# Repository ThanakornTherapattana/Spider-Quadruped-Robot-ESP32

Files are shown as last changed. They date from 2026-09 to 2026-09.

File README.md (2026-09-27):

# Spider Quadruped Robot

I built this cute spider robot from scratch with esp32 and lots of determination. by trials and errors, this robot improve bit by bit...

this is still experimental project, not a finished one yet!

## Components
12 x mg996R servo
1 x esp32 wroom
1 x 7.4V 2200mAh lipo battery
2 x PCA9685 driver
1 x 3.3v buck converter
1 x 20A buck converter
2 x 2200uF 10V capacitor
1 x MPU6050
M2/M3 screws and heat insertion set
3D printed parts (can be download in 3D models folder)

## how to run
### 1) Servo calibration
I don't have the calibration file uploaded here but you can do it by setting Coxa and Femur joint to 90 degree and Tibia to 0 degree.
### 2) Assemble 
copy this image. the leg should be stretch out like this
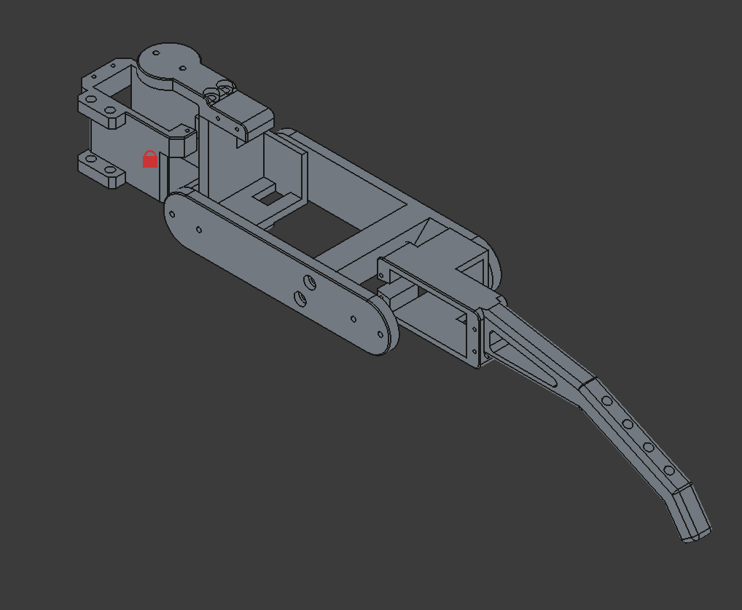
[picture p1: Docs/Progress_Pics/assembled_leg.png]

### 3) Movement TEST (No MPU6050 needed)
you can run the IK_test.ino file first for one leg.
the leg will follow a cycloidal curve to perform a step.
after that you can move-on to 1legs_test.ino (you have to fully assemble the robot)


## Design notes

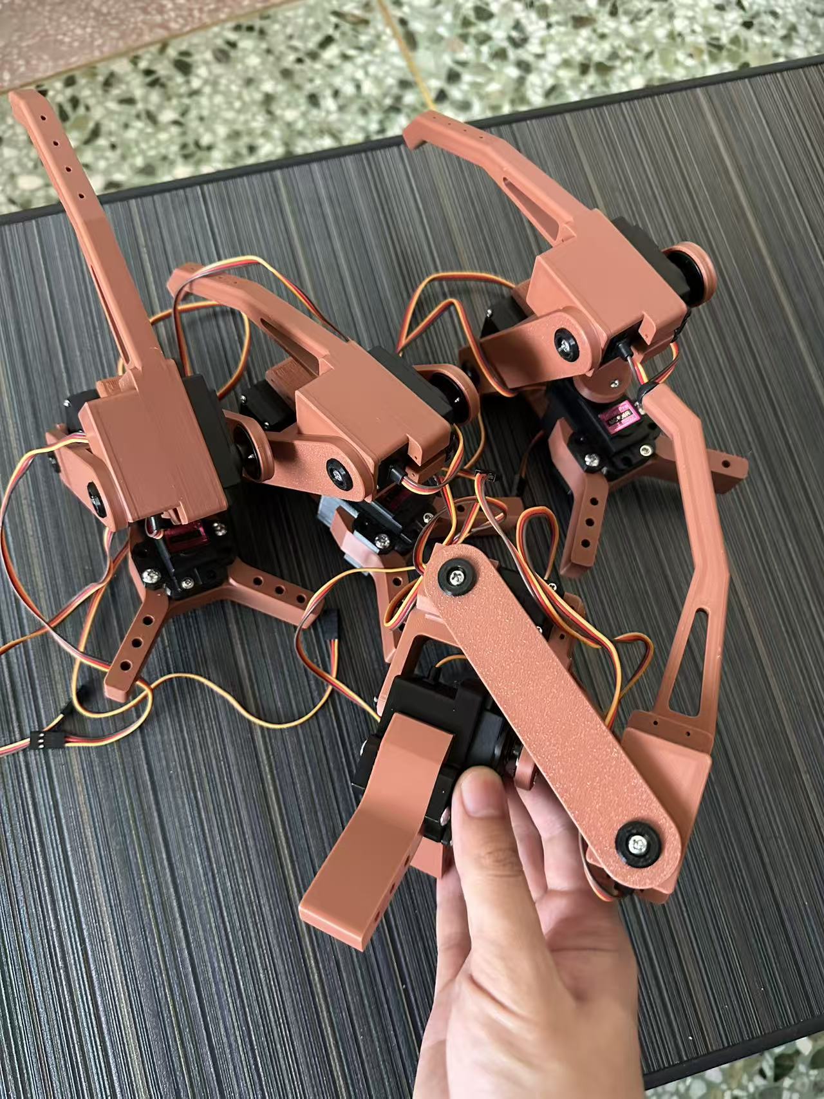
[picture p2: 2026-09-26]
Docs/Progress_Pics/Weixin Image_20260918160550_50_58.jpg

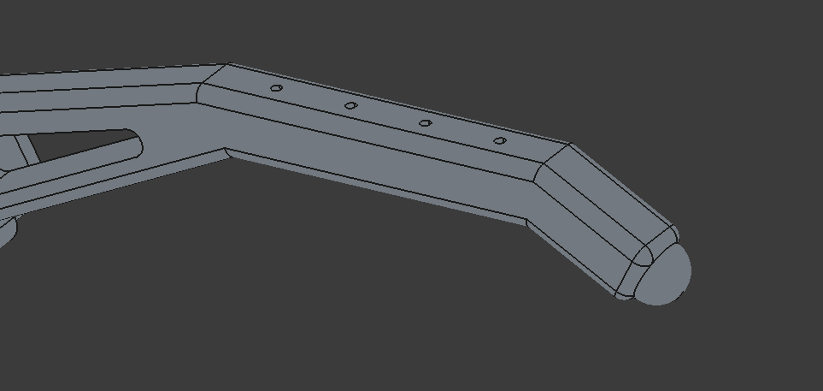
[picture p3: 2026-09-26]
Docs/Progress_Pics/Screenshot 2026-05-20 154046.png

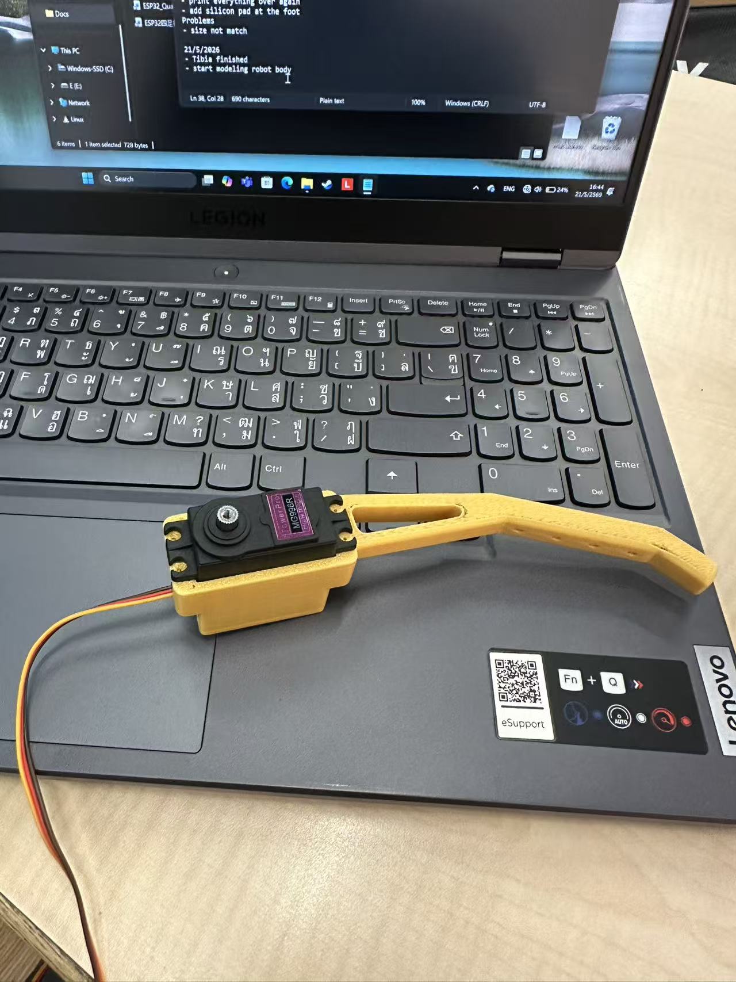
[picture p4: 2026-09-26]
Docs/Progress_Pics/Weixin Image_20260521164413_180_100.jpg

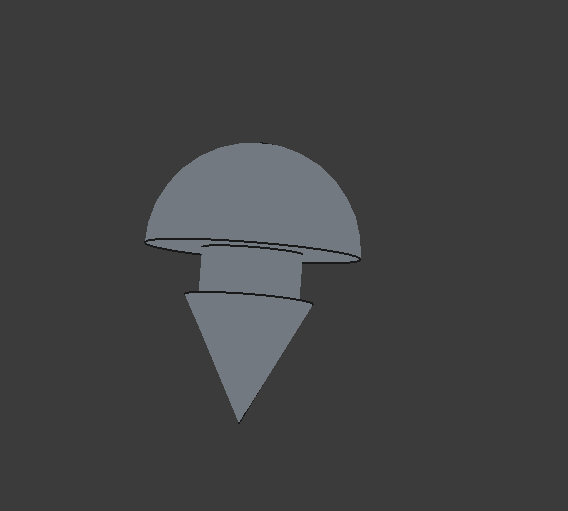
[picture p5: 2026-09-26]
Docs/Progress_Pics/Screenshot 2026-05-20 144256.png

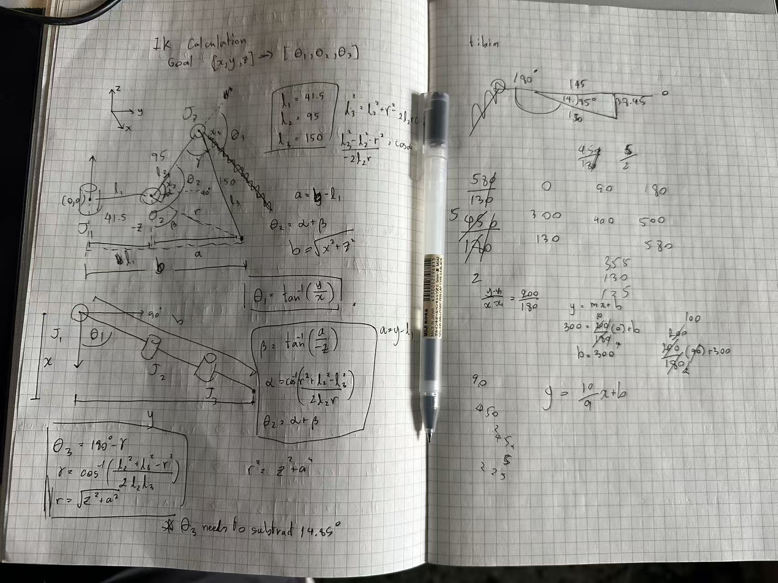
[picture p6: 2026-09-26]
Docs/Progress_Pics/Weixin Image_20260526165921_192_100.jpg

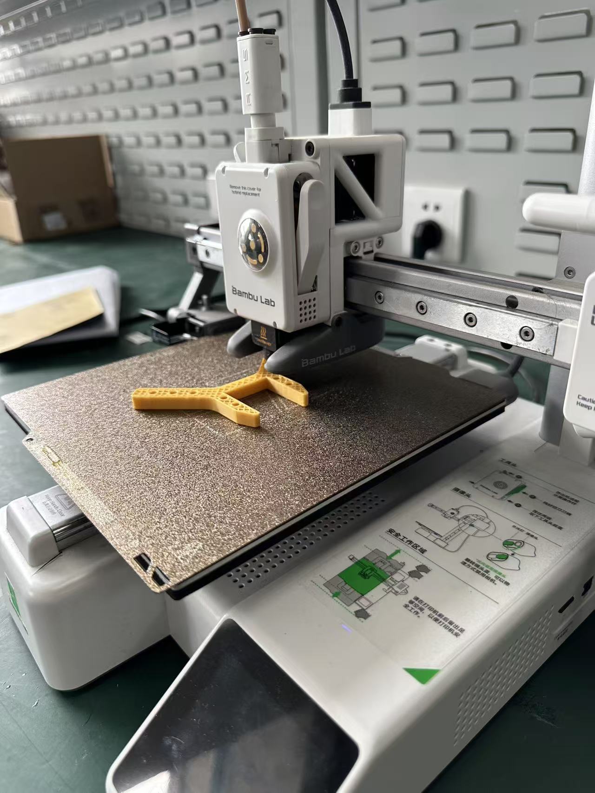
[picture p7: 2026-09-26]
Docs/Progress_Pics/Weixin Image_20260522120751_183_100.jpg

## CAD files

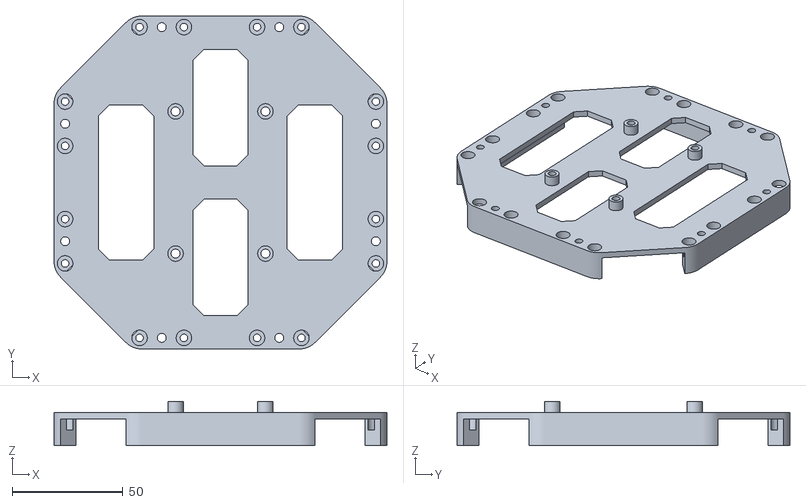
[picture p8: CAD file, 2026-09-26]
3D models/body_files/first_leg-bodyTop.stl
150.0 x 150.0 x 20.0

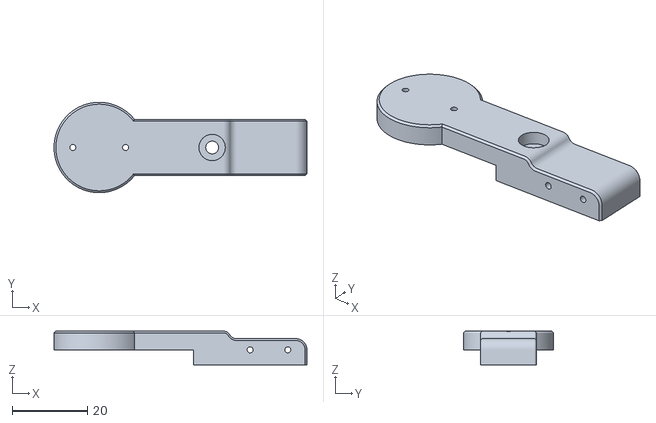
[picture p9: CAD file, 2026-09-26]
3D models/newPrint_files/first_leg-newCoxaTop.stl
67.2 x 24.0 x 9.00

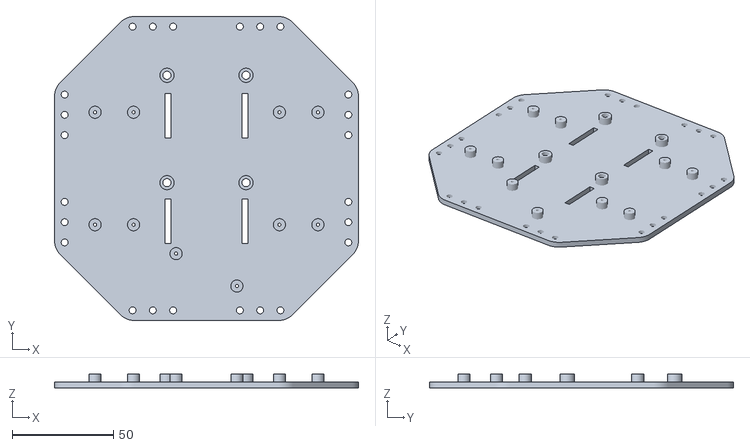
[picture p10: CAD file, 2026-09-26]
3D models/body_files/first_leg-bodyBottom.stl
150.0 x 150.0 x 7.00

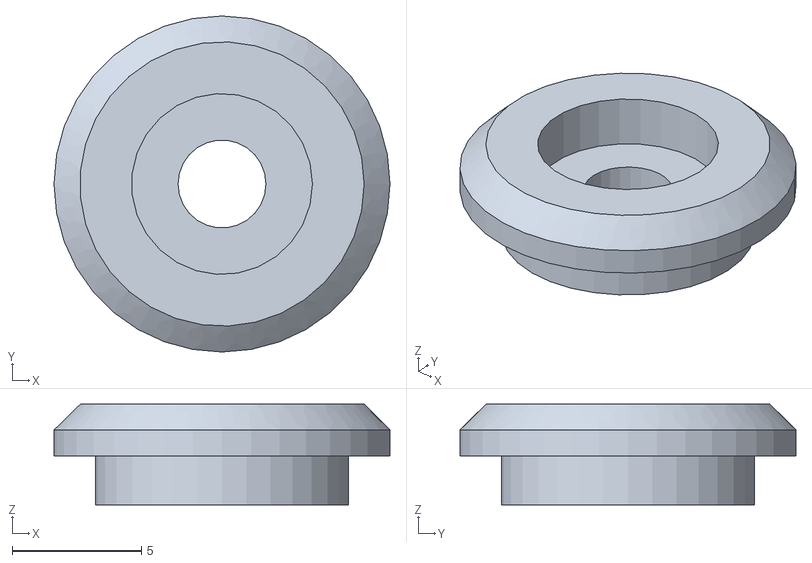
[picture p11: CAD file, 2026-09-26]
3D models/newPrint_files/first_leg-FrictionPad.stl
13.0 x 13.0 x 3.90

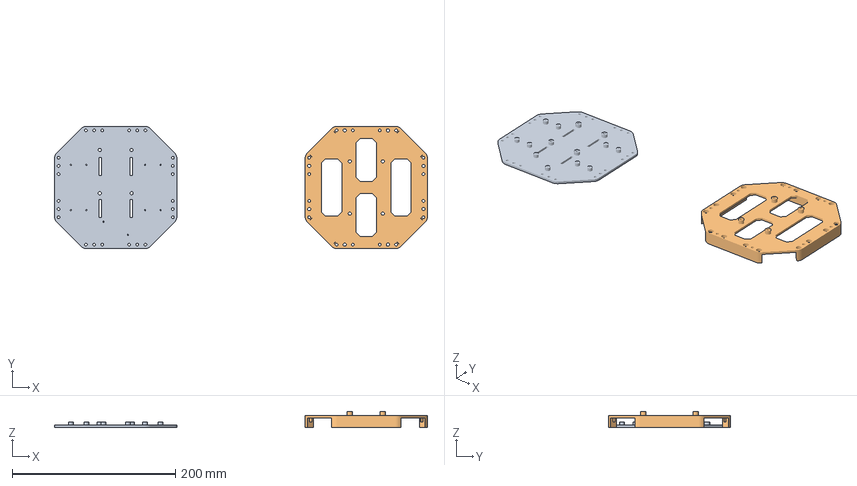
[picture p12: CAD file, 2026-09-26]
3D models/body_files/body_plates.3mf
457.2 x 150.0 x 20.0 mm
first_leg-bodyBottom.stl
first_leg-bodyTop.stl

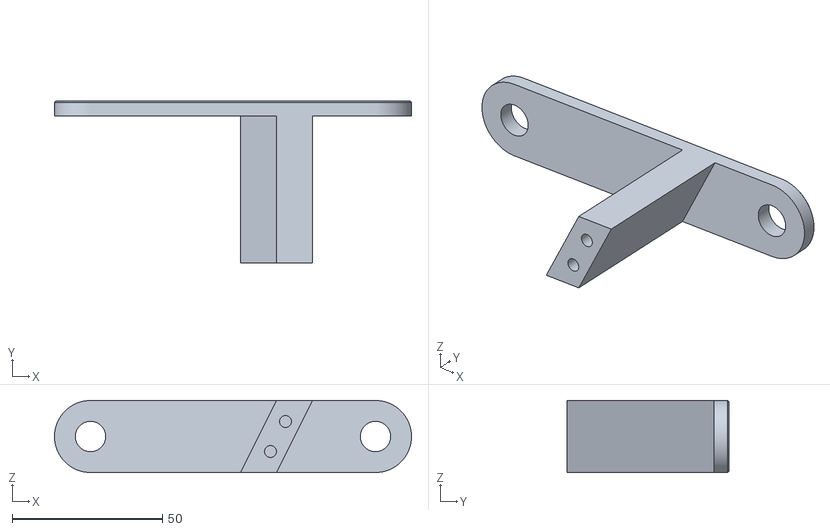
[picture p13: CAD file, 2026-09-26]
3D models/newPrint_files/first_leg-FemurBottom.stl
119.0 x 54.0 x 24.0

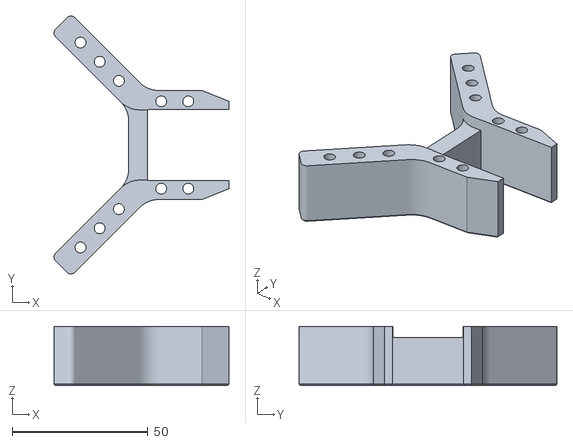
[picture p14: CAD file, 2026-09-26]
3D models/newPrint_files/first_leg-coxaHolder.stl
64.5 x 95.1 x 21.8

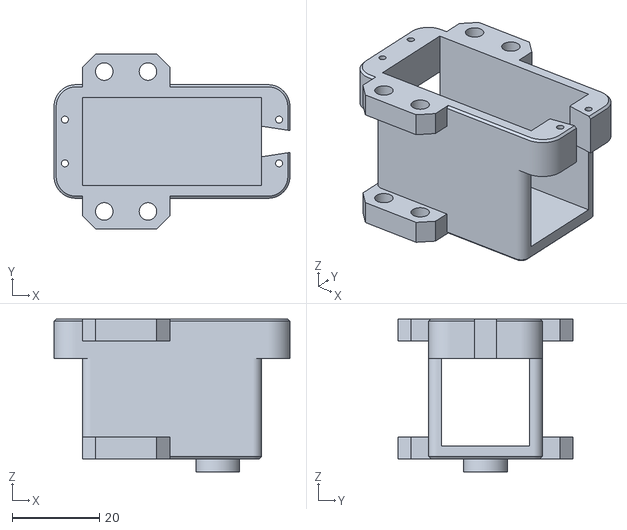
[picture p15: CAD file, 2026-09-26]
3D models/newPrint_files/first_leg-newCoxaServoMount.stl
54.0 x 40.0 x 35.0

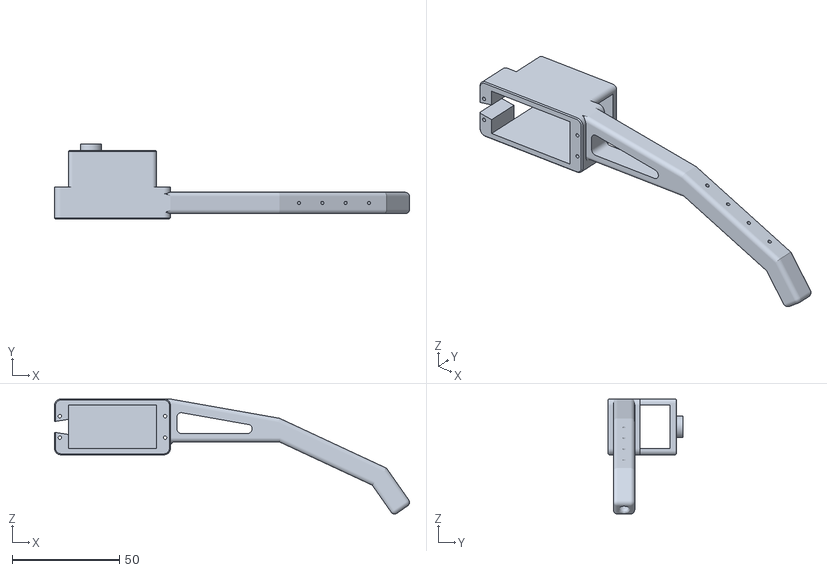
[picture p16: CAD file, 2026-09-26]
3D models/newPrint_files/first_leg-newTibia001.stl
165.3 x 35.0 x 53.5

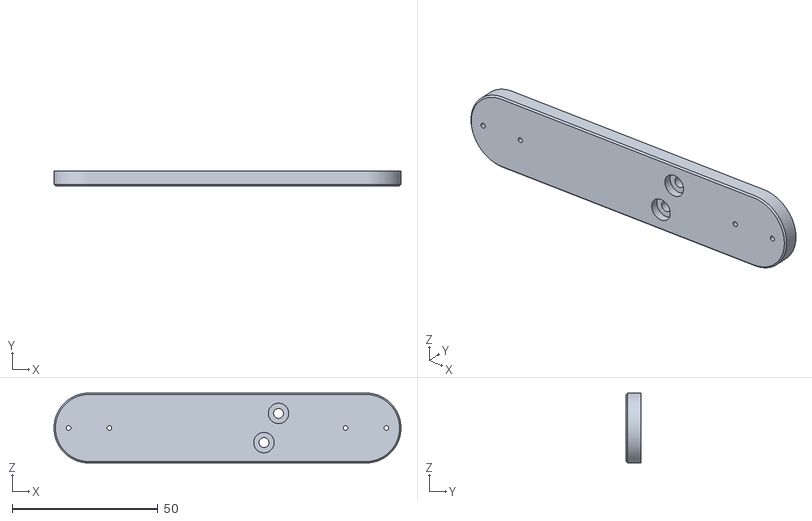
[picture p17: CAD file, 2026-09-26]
3D models/newPrint_files/first_leg-FemurTop.stl
119.0 x 5.00 x 24.0

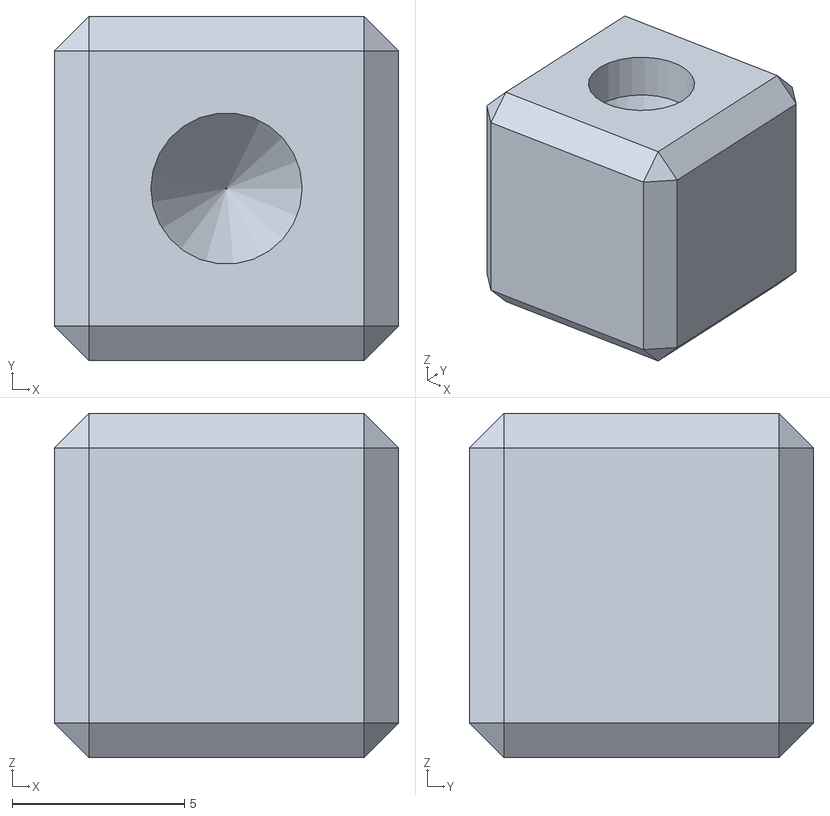
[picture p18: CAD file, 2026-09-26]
3D models/newPrint_files/footPadtest-Body.stl
10.0 x 10.0 x 10.0

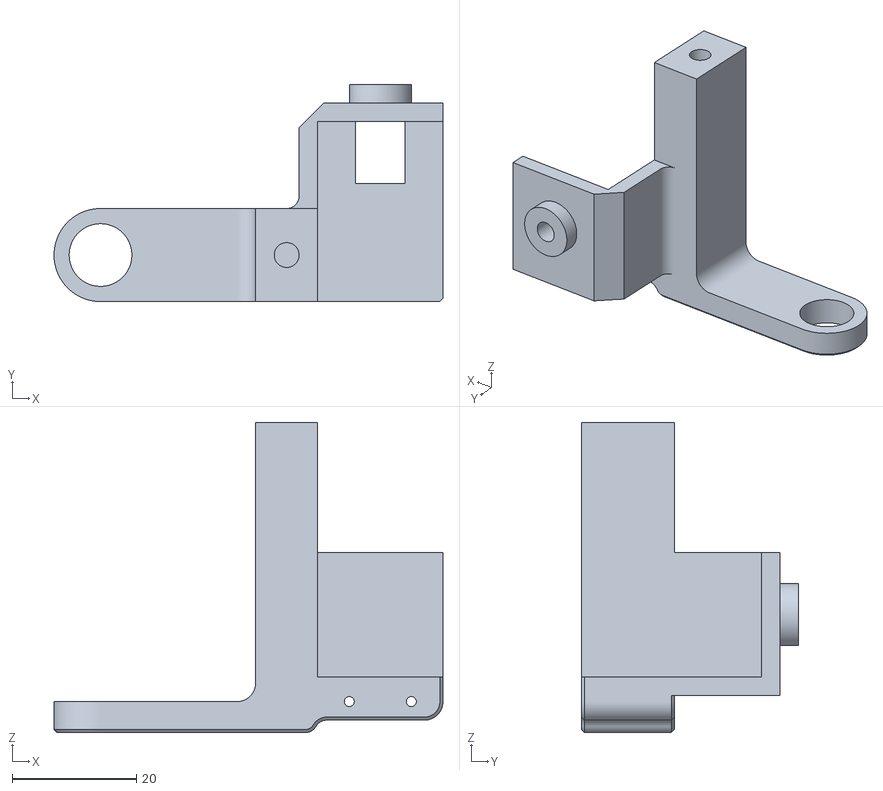
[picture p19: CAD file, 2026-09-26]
3D models/newPrint_files/first_leg-newCoxaBottom.stl
62.7 x 35.0 x 50.0

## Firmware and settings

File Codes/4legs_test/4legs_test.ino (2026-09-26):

#include <Wire.h>
#include <Adafruit_PWMServoDriver.h>
#include <math.h>

Adafruit_PWMServoDriver pwm1 = Adafruit_PWMServoDriver(0x40);
Adafruit_PWMServoDriver pwm2 = Adafruit_PWMServoDriver(0x41);

// servo setup
#define SERVOMIN 130
#define SERVOMAX 580
#define SERVO_FREQ 50


// Link lengths
const float coxa = 41.5;
const float femur = 95.0;
const float tibia = 150.0;

// Link Angles
float theta1, theta2, theta3;


// Others Mathematical Variable
//const float PI = 3.1415;
const float tibia_offset = 14;
const int step_num = 40;
const float step_length = 100.0;
const float step_height = 30.0;

// foot home and still coordinate
float x,y,z;
float X_home = 0;
float Y_home = 115;
float Z_home = -35;
float X_still = 0;
float Y_still = 170;
float Z_still = -50;

void coord_calculation(){
  float x_start = -step_length/2;
  float x_end = step_length/2;

  float rx = step_length/(2*PI);
  float rz = step_height/2;

//cycloidal lift
  for(int step=0; step<=step_num; step++){
    float t = (float)step/step_num;
    x = x_end - rx*(2*PI*t - sin(2*PI*t));
    y = Y_still;
    z = rz*(1.0 - cos(2*PI*t)) + Z_still;

    IK_calculation(x, y, z);
    writeFR(theta1, theta2, theta3);
    delay(15);
  }

//linear push back
  for(int step=0; step<=step_num; step++){
    float t = (float)step/step_num;
    x = t*step_length + x_start;
    y = Y_still;
    z = Z_still;

    IK_calculation(x, y, z);
    writeFR(theta1, theta2, theta3);
    delay(15);
  }
}

void updown_move(){
  //down
  for(int z = Z_still; z>=-100; z--){
    IK_calculation(X_still, Y_still, z);
    writeFR(theta1, theta2, theta3);
    writeBR(theta1, theta2, theta3);
    writeFL(theta1, theta2, theta3);
    writeBL(theta1, theta2, theta3);
    delay(15);
  }
  delay(1000);
  //up
  for(int z = -100; z<=-50; z++){
    IK_calculation(X_still, Y_still, z);
    writeFR(theta1, theta2, theta3);
    writeBR(theta1, theta2, theta3);
    writeFL(theta1, theta2, theta3);
    writeBL(theta1, theta2, theta3);
    delay(15);
  }
  delay(1000);
}

void writeFR(int FR1, int FR2, int FR3) {
  pwm1.setPWM(13, 0, angleToPulse(FR1));
  pwm1.setPWM(14, 0, angleToPulse(FR2));
  pwm1.setPWM(15, 0, angleToPulse(FR3));
}
void writeFL(int FL1, int FL2, int FL3) {
  pwm2.setPWM(0, 0, angleToPulse(FL1));
  pwm2.setPWM(1, 0, angleToPulse(FL2));
  pwm2.setPWM(2, 0, angleToPulse(FL3));
}
void writeBR(int BR1, int BR2, int BR3) {
  pwm1.setPWM(0, 0, angleToPulse(BR1));
  pwm1.setPWM(1, 0, angleToPulse(BR2));
  pwm1.setPWM(2, 0, angleToPulse(BR3));
}
void writeBL(int BL1, int BL2, int BL3) {
  pwm2.setPWM(13, 0, angleToPulse(BL1));
  pwm2.setPWM(14, 0, angleToPulse(BL2));
  pwm2.setPWM(15, 0, angleToPulse(BL3));
}

int angleToPulse(float ang){
  int pulse = ang*2.5+130;
  pulse = constrain(pulse, SERVOMIN, SERVOMAX);
  return pulse;
}

void IK_calculation(float x, float y, float z){
  float b = sqrt(x*x+y*y);
  float a = b-coxa;
  float r = sqrt(z*z+a*a);
  float theta2_cos = (r*r + femur*femur - tibia*tibia) / (2*femur*r);
  float theta3_cos = (femur*femur + tibia*tibia - r*r) / (2*femur*tibia);

  theta1 = atan2(y, x)*180.0/PI;
  theta2 = ( acos(constrain(theta2_cos, -1.0, 1.0)) + atan2(a, -z) )*180.0/PI;
  theta3 = 180.0 - tibia_offset - acos(constrain(theta3_cos, -1.0, 1.0))*180.0/PI;

  theta1 = constrain(theta1, 0, 180);
  theta2 = constrain(theta2, 0, 180);
  theta3 = constrain(theta3, 0, 135);

}

void setup() {
  // put your setup code here, to run once:
  Serial.begin(9600);
  Serial.println("Inverse Kinematic TEST!");

  pwm1.begin();
  pwm1.setPWMFreq(SERVO_FREQ);
  pwm2.begin();
  pwm2.setPWMFreq(SERVO_FREQ);

  IK_calculation(X_still, Y_still, Z_still);
  writeFR(theta1, theta2, theta3);
  delay(3000);


}

void loop() {
  // put your main code here, to run repeatedly:
  if ( Serial.available()){
    float x = Serial.parseFloat();
    float y = Serial.parseFloat();
    float z = Serial.parseFloat();

    IK_calculation(x, y, z);
    writeFR(theta1, theta2, theta3);
  }
  updown_move();

  
}

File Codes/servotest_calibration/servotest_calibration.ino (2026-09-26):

#include <Wire.h>
#include <Adafruit_PWMServoDriver.h>

Adafruit_PWMServoDriver pwm = Adafruit_PWMServoDriver();

#define SERVOMIN 130
#define SERVOMAX 580
#define SERVO_FREQ 50


int angleToPulse(float ang){
  int pulse = ang*5/2+130;
  pulse = constrain(pulse, SERVOMIN, SERVOMAX);
  Serial.print("Angle: ");Serial.print(ang);
  Serial.print(" pulse: ");Serial.println(pulse);
  return pulse;
}

void setup() {
  // put your setup code here, to run once:
  Serial.begin(9600);
  Serial.println("servo test!");

  pwm.begin();
  pwm.setPWMFreq(SERVO_FREQ);

}


void loop() { 
  // put your main code here, to run repeatedly:
  if ( Serial.available()){
    float x = Serial.parseFloat();
    float y = Serial.parseFloat();
    float z = Serial.parseFloat();
    pwm.setPWM(0, 0, angleToPulse(x) );
    pwm.setPWM(1, 0, angleToPulse(y) );
    pwm.setPWM(2, 0, angleToPulse(z) );
    }
  
  delay(500);
}

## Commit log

2026-09-27 Rename Screenshot 2026-05-16 213953.png to assembled leg
2026-09-27 Rename assembled leg to assembled_leg.png
